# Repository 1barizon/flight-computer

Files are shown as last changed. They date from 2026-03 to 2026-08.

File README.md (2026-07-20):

# Avionics — Onboard Computer

> **v2.0 Flight Computer** for Serra Rocketry (#11 - Dedalo).
>
> OOP + FreeRTOS + 4-state FSM, validated against real flight data.
> Built for the ESP32-S3.

## Overview

Real-time avionics firmware for a sounding rocket. Runs on an **ESP32-S3**
under FreeRTOS, reading barometric (BMP585), inertial (LSM6DS3) and GPS
(NEO-8M) sensors to detect flight events and deploy the parachute at apogee.

- **Flight state machine**: IDLE → ASCENT → DESCENT → LANDED, with sub-event
  flags (liftoff, burnout, apogee, freefall, parachute)
- **Parachute deployment**: Apogee + stable negative Vz, 3-cycle
  confirmation, 50 m ground guard — validated against RocketPy + real flight data points
- **Telemetry**: 22-field CSV over LoRa @ 915 MHz to ground receiver
- **Logging**: SD card (primary) with LittleFS flash fallback
- **Safety**: NaN/Inf rejection, sensor fallback, TWDT watchdog, multi-condition parachute logic

## Architecture

```
firmware/
├── firmware.ino          # setup()/loop() — orchestrates init*Task()
├── config.h              # Pins, thresholds, radio parameters
├── sensors/              # ISensor implementations (BMP585, LSM6DS3, GPS)
├── flight/               # FreeRTOS tasks + FlightStateMachine
├── modules/              # Actuators/peripherals (servo, LoRa, buzzer, FS)
├── MODULOS.md            # Module reference
└── REFACTORING_PLAN.md   # v2.0 architecture specification
```

Two FreeRTOS cores with queue-based communication:

| Core | Task | Priority | Rate | Responsibility |
|---|---|---|---|---|
| **1** | `FlightControlTask` | 20 | 50 Hz | Sensors + FSM + parachute + watchdog |
| **0** | `TelemetryTask` | 5 | 5 Hz | GPS enrichment + LoRa + file + Serial |
| **0** | `LoggerTask` | 1 | — | Async log queue with level filter |

## Quick Start

### Arduino IDE (recommended)

1. Board: **ESP32-S3 Dev Module** (enable "USB CDC On Boot")
2. Open `firmware/firmware.ino`
3. Install libraries: `Adafruit BMP5xx`, `Adafruit LSM6DS3`, `TinyGPS++`,
   `ESP32Servo`, `LoRa by Sandeep Mistry`
4. Compile (`Ctrl+R`) and upload (`Ctrl+U`)

### Validate without hardware

```bash
python3 extras/FSM_tester/FSM_Tester.py       # FSM against 1,873 real data points
python3 extras/validate_telemetry_format.py    # 22-field telemetry alignment
```

## Key Specifications

| Parameter | Value |
|---|---|
| FlightControl rate | 50 Hz (20 ms) |
| Telemetry rate | 5 Hz (200 ms) |
| Parachute confirm | 3 consecutive Vz < −2 m/s |
| Ground guard | 50 m AGL |
| LoRa frequency | 915 MHz (Brazil/Americas ISM) |
| LoRa config | SF7, BW 125 kHz, CR 4/5, CRC on, +17 dBm |
| Storage | SD card (SPI) → LittleFS fallback |
| Sensor queue | 25 slots (∼2.4 KB) |
| Log queue | 50 slots (∼7.2 KB) |

## Documentation

- [`docs/software.md`](docs/software.md) — Software architecture
- [`docs/hardware.md`](docs/hardware.md) — Hardware specs, pinout, BOM
- [`docs/flowchart.md`](docs/flowchart.md) — FreeRTOS + FSM flow diagram
- [`AGENTS.md`](AGENTS.md) — AI agent coding guide
- [`CONTRIBUTING.md`](CONTRIBUTING.md) — How to contribute

## Repository Layout

```
firmware/   v2.0 firmware (OOP + FreeRTOS + FSM)
test/       Hardware validation sketches (sensors, servo, FSM)
docs/       software.md, hardware.md, telemetry-format.md, flowchart.md
hardware/   KiCad schematic + PCB + BOM
extras/     Scripts, FSM tester, format validator
```

## Status

All refactoring plan phases are **complete** — v2.0 is fully implemented and
documented. See [`CHANGELOG.md`](CHANGELOG.md) for the full release history.

## Team

Serra Rocketry — #11 Dedalo - LASC 2026

## License

Serra Rocketry. Contributions under the project license — see `CONTRIBUTING.md`.

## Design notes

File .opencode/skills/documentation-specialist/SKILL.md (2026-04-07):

---
name: documentation-specialist
description: Technical writer and documentation specialist for embedded systems and aerospace projects.
license: MIT
compatibility: opencode
---

## Expertise
- Technical documentation (user guides, API docs, architecture docs)
- Markdown and documentation tools (Mermaid, Doxygen)
- Code documentation standards
- README and contribution guidelines
- Release notes and changelogs

## Responsibilities
1. **Maintain Project Documentation**
   - Keep README.md up to date
   - Update CHANGELOG.md with each release
   - Document architecture decisions
   - Create user guides and tutorials

2. **Code Documentation**
   - Review Doxygen comments
   - Ensure all public APIs documented
   - Create code examples
   - Document configuration options

3. **Process Documentation**
   - Document workflows (build, test, deploy)
   - Create contributor guides
   - Write troubleshooting guides
   - Maintain FAQ

## Project Documentation Structure

```
flight-computer/
├── README.md                    # Project overview
├── CHANGELOG.md                 # Version history
├── CONTRIBUTING.md              # How to contribute
│
├── docs/
│   ├── hardware.md              # Hardware specifications
│   ├── software.md              # Software architecture
│   ├── flowchart.md             # System flowcharts
│   └── CDB.png                  # Block diagram
│
├── firmware/
│   ├── MODULOS.md               # Module documentation
│   ├── REFACTORING_PLAN.md      # v2.0 architecture
│   └── [code files with Doxygen comments]
│
└── extras/
    └── FSM_tester/
        └── explicacao.md        # FSM explanation
```

## Documentation Standards

### README.md Structure
```markdown
# Project Name

[Badge: Build Status] [Badge: License] [Badge: Version]

## Overview
Brief description of the project (2-3 sentences)

## Features
- Feature 1
- Feature 2

## Hardware Requirements
- Component 1
- Component 2

## Software Requirements
- Library 1
- Library 2

## Quick Start
1. Step 1
2. Step 2

## Documentation
- [Hardware Guide](docs/hardware.md)
- [Software Guide](docs/software.md)

## Contributing
See [CONTRIBUTING.md](CONTRIBUTING.md)

## License
[License information]

## Team
Team #100 - Serra Rocketry
```

### CHANGELOG.md Format
**Follow**: [Keep a Changelog](https://keepachangelog.com/)

```markdown
# Changelog

All notable changes to this project will be documented in this file.

The format is based on [Keep a Changelog](https://keepachangelog.com/en/1.0.0/),
and this project adheres to [Semantic Versioning](https://semver.org/spec/v2.0.0.html).

## [Unreleased]

### Added
- New feature X

### Changed
- Modified behavior Y

### Fixed
- Bug Z

## [2.0.0] - 2026-XX-XX

### Added
- FreeRTOS multi-task architecture
- 7-state FSM with validated thresholds
- BMP585 and LSM6DS3 sensor support
- OOP sensor abstractions (ISensor interface)

### Changed
- Migrated from procedural to OOP design
- Replaced BMP280 with BMP585
- Replaced MPU6050 with LSM6DS3

### Removed
- Old procedural sensor modules

## [1.0.0] - 2026-01-27

### Added
- Initial release
- BMP280 barometric sensor support
- MPU6050 IMU support
- GPS NEO-6M integration
- LoRa telemetry (RFM95W)
- Parachute deployment logic
- LittleFS data logging
- WiFi AP for data recovery

[Unreleased]: https://github.com/team100/flight-computer/compare/v2.0.0...HEAD
[2.0.0]: https://github.com/team100/flight-computer/compare/v1.0.0...v2.0.0
[1.0.0]: https://github.com/team100/flight-computer/releases/tag/v1.0.0
```

### Code Documentation (Doxygen)

#### File Header
```cpp
/**
 * @file BMP585Sensor.h
 * @brief BMP585 barometric pressure sensor driver with altitude calculation
 * 
 * This module provides an interface to the Bosch BMP585 barometric pressure
 * sensor. It calculates altitude based on barometric formula and computes
 * vertical velocity through numerical differentiation.
 * 
 * @author Team #100 - Serra Rocketry
 * @date 2026-04-01
 * @version 2.0.0
 * 
 * Hardware Requirements:
 * - BMP585 sensor connected via I2C
 * - I2C address: 0x77 (SDO high) or 0x76 (SDO low)
 * - Pull-up resistors: 4.7kΩ (internal to ESP32-C3)
 * 
 * Usage Example:
 * @code
 * BMP585Sensor baro;
 * 
 * void setup() {
 *   if (!baro.begin()) {
 *     Serial.println("Sensor initialization failed");
 *   }
 * }
 * 
 * void loop() {
 *   baro.update();
 *   float alt = baro.getAltitude();
 *   float vz = baro.getVerticalVelocity();
 * }
 * @endcode
 * 
 * @see firmware/REFACTORING_PLAN.md for architecture details
 * @see docs/hardware.md for wiring diagram
 */
```

#### Function Documentation
```cpp
/**
 * @brief Initializes the BMP585 sensor and calibrates base pressure
 * 
 * This function performs the following steps:
 * 1. Establishes I2C communication with sensor
 * 2. Verifies sensor ID (0x50 for BMP585)
 * 3. Configures oversampling and IIR filter
 * 4. Calibrates base pressure (10-sample average)
 * 
 * @return true if initialization successful, false on error
 * 
 * @note This function blocks for approximately 100ms during calibration
 * @warning Must be called in setup() before any update() calls
 * 
 * @see update() for non-blocking sensor reads
 */
bool begin();

/**
 * @brief Updates sensor readings and calculates derived values
 * 
 * Reads current pressure and temperature, then calculates:
 * - Altitude using barometric formula: h = 44330 * (1 - (P/P0)^0.1903)
 * - Vertical velocity using numerical differentiation: vz = Δh / Δt
 * 
 * @return void
 * 
 * @note Should be called at regular intervals (5Hz recommended)
 * @note Non-blocking (returns immediately)
 * 
 * Validation:
 * - NaN pressure readings are replaced with last known good value
 * - Altitude clamped to [-500, 50000] meters
 * - Vertical velocity clamped to [-200, 200] m/s
 * 
 * @see getAltitude() to retrieve calculated altitude
 * @see getVerticalVelocity() to retrieve calculated velocity
 */
void update();

/**
 * @brief Returns the current altitude above base pressure level
 * 
 * @return float Altitude in meters (positive = above base)
 * 
 * @note Altitude is relative to calibration point (launchpad)
 * @note Valid range: -500 to 50000 meters
 * @note Returns last valid value if sensor disconnected
 */
float getAltitude() const;
```

### Architecture Documentation

#### Decision Record Template
**File**: `docs/adr/001-freertos-migration.md`

```markdown
# ADR 001: Migrate to FreeRTOS Architecture

**Status**: Accepted  
**Date**: 2026-03-15  
**Deciders**: Team #100  

## Context
Current v1.0 firmware uses single-threaded Arduino loop() running at 5Hz.
This creates several issues:
1. Slow FSM response time (200ms loop period)
2. Cannot prioritize flight-critical tasks
3. Telemetry logging blocks flight control
4. Underutilizes ESP32 dual-core processor

## Decision
Migrate to FreeRTOS multi-task architecture with 3 tasks:
- **FlightControl**: 50Hz, Core 1, Priority 20 (flight-critical)
- **Telemetry**: 5Hz, Core 0, Priority 5 (non-critical)
- **Logger**: Low priority, Core 0 (background)

## Rationale
- **Real-time response**: 20ms FSM update vs 200ms previously
- **Prioritization**: Flight safety takes precedence over logging
- **Core separation**: Flight logic isolated from I/O operations
- **Scalability**: Easy to add tasks (e.g., camera control)

## Consequences

### Positive
- 10x faster FSM response time
- Flight control never blocked by slow operations
- Better CPU utilization (both cores active)
- Industry-standard RTOS patterns

### Negative
- Increased complexity (task synchronization)
- Higher RAM usage (~15KB for RTOS overhead)
- Requires mutex/queue understanding
- Longer development time (estimated +8 hours)

## Alternatives Considered
1. **Keep single-threaded** - Rejected: Too slow for safety-critical FSM
2. **Custom cooperative scheduler** - Rejected: Reinventing the wheel
3. **Bare metal dual-core** - Rejected: Complex synchronization

## Implementation
See `firmware/REFACTORING_PLAN.md` Phase 7 for details.

## References
- ESP32 Technical Reference Manual, Chapter 3 (RTOS)
- FreeRTOS Documentation: Task Priorities
- Similar implementation: Teensy Flight Computer (MIT Rocket Team)
```

### Mermaid Diagrams

#### FSM State Diagram
```markdown
## Flight State Machine

```mermaid
stateDiagram-v2
    [*] --> IDLE
    IDLE --> LIFTOFF: totalAccel > 15 m/s²<br/>height > 5m
    
    LIFTOFF --> BURNOUT: az < -8 m/s² OR<br/>totalAccel < 2 m/s²
    
    BURNOUT --> APOGEE: |vz| < 1 m/s AND<br/>az < -0.1 m/s²
    
    APOGEE --> FREEFALL: totalAccel < 11.5 m/s² AND<br/>vz < -5 m/s
    
    FREEFALL --> PARACHUTE: altitude < 750m OR<br/>|vz| > 80 m/s
    
    PARACHUTE --> LANDED: |vz| < 0.5 m/s AND<br/>height < 10m
    
    LANDED --> [*]
    
    note right of IDLE
        Initialize sensors
        Calibrate base pressure
    end note
    
    note right of PARACHUTE
        Deploy parachute
        Start WiFi AP
        Beacon buzzer
    end note
\```
```

#### Task Interaction Diagram
```markdown
## FreeRTOS Task Architecture

```mermaid
graph TB
    subgraph "Core 1 - Flight Critical"
        FC[FlightControl Task<br/>50Hz, Priority 20]
        FSM[Flight State Machine]
        SENS[Sensor Updates]
        PARA[Parachute Control]
        
        FC --> FSM
        FC --> SENS
        FSM --> PARA
    end
    
    subgraph "Core 0 - Non-Critical"
        TEL[Telemetry Task<br/>5Hz, Priority 5]
        LOG[Logger Task<br/>Low Priority]
        
        TEL --> LORA[LoRa Transmit]
        TEL --> SERIAL[Serial Output]
        LOG --> FS[File System]
    end
    
    subgraph "Shared Resources"
        QUEUE[(Sensor Data Queue)]
        MUTEX{Altitude Mutex}
    end
    
    FC -->|xQueueSend| QUEUE
    TEL -->|xQueueReceive| QUEUE
    
    FC -->|xSemaphoreTake| MUTEX
    TEL -->|xSemaphoreTake| MUTEX
    
    style FC fill:#f96,stroke:#333,stroke-width:2px
    style TEL fill:#9cf,stroke:#333,stroke-width:2px
    style LOG fill:#9cf,stroke:#333,stroke-width:2px
\```
```

## Documentation Review Checklist

### For New Features
- [ ] README.md updated with feature description
- [ ] CHANGELOG.md updated (Unreleased section)
- [ ] API documentation (Doxygen comments)
- [ ] Usage examples provided
- [ ] Hardware requirements documented (if applicable)
- [ ] Configuration options explained

### For Bug Fixes
- [ ] CHANGELOG.md updated (Fixed section)
- [ ] Root cause documented in issue/PR
- [ ] Prevention strategy explained

### For Refactoring
- [ ] Architecture Decision Record created
- [ ] Migration guide provided
- [ ] Breaking changes documented
- [ ] CHANGELOG.md updated (Changed section)

## Tools

### Generate Doxygen Docs
```bash
# Install Doxygen
sudo apt install doxygen graphviz

# Generate documentation
cd firmware
doxygen Doxyfile

# View in browser
firefox html/index.html
```

### Mermaid Live Editor
https://mermaid.live/

### Markdown Linting
```bash
# Install markdownlint
npm install -g markdownlint-cli

# Lint documentation
markdownlint docs/**/*.md
```

## Resources
- Project documentation: `docs/`
- Doxygen manual: https://www.doxygen.nl/
- Mermaid syntax: https://mermaid.js.org/
- Keep a Changelog: https://keepachangelog.com/
- Semantic Versioning: https://semver.org/

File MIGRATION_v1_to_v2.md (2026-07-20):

# Migration Guide: v1.0 → v2.0 (Flight Computer)

This document records the architectural decisions and concrete changes made
when moving the Flight Computer firmware from the v1.0 procedural design
(branch `main`, pre-refactor) to the v2.0 OOP + FreeRTOS design (branch
`dev-2026`). It is the rationale companion to `REFACTORING_PLAN.md` and the
`docs/` files — read it when you need to understand *why* something changed,
not just *what* the code looks like now.

## TL;DR

| Aspect | v1.0 (main, legacy) | v2.0 (dev-2026) |
|---|---|---|
| Architecture | Procedural `loop()` in one `firmware.ino` (~680 lines) | OOP + FreeRTOS, modular `sensors/` `modules/` `flight/` |
| Sensors | BMP280 + MPU6050 + NEO-6M | BMP585 + LSM6DS3 + NEO-8M |
| Flight logic | `handleParachute()` with altitude ceiling | `FlightStateMachine` (4 states + 7 sub-events) |
| Parachute | Deploy at `ALTITUDE_THRESHOLD = 750 m` | Deploy at **apogee** |
| Comms | LoRa 868 MHz, ad-hoc CSV | LoRa 915 MHz, v2.0 22-field format |
| Web UI | ESPAsyncWebServer on board | Removed (receiver provides web UI) |
| Storage | LittleFS, v1.0 CSV header | SD card (filesystem_module.h `setupStorage`), LittleFS fallback; 22-field v2.0 CSV |

## Side-by-side: Architecture

### Project structure

**v1.0** — flat, monolithic:

```
firmware/
├── firmware.ino              # ~680 lines: setup() + loop() + all logic
├── config.h
├── data/server/              # ESPAsyncWebServer web UI (index.html/js/css)
├── bmp280_sensor.h           # legacy sensor module
├── mpu6050_sensor.h
├── gps_module.h
├── lora_module.h
├── filesystem_module.h
├── parachute_module.h
└── buzzer_module.h
```

**v2.0** — modular OOP + FreeRTOS:

```
firmware/
├── firmware.ino              # thin entry point: setup() calls init*Task()
├── config.h                  # pins, thresholds, LoRa params
├── sensors/                  # ISensor abstraction
│   ├── ISensor.h
│   ├── BMP585Sensor.h/.cpp
│   ├── LSM6DS3Sensor.h/.cpp
│   └── GPSModule.h/.cpp
├── modules/                  # actuators / peripherals
│   ├── parachute_module.h    # owns ParachuteServo
│   ├── lora_module.h
│   ├── buzzer_module.h
│   └── filesystem_module.h
└── flight/                   # FreeRTOS tasks + FSM
    ├── SensorData.h
    ├── FlightStateMachine.h/.cpp
    ├── FlightControlTask.h/.cpp
    ├── TelemetryTask.h/.cpp
    └── LoggerTask.h/.cpp
```

### Data flow

**v1.0** — synchronous, single thread:

```
loop() [every INTERVAL ms]
  └─ readSensors()        # blocking I2C/UART reads
       └─ handleParachute()   # direct servo write if alt < 750 m
            └─ logData()      # append to LittleFS
                 └─ sendLoRa() # one long CSV string
```

**v2.0** — concurrent, queue-driven:

```
Core 1 (50 Hz, prio 20):  taskFlightControl
  ├─ BMP585/LSM6DS3 update()
  ├─ FlightStateMachine.update()  → detectParachute() at apogee
  ├─ deployParachute() via parachute_module
  └─ xQueueSend(sensorDataQueue)

Core 0 (5 Hz, prio 5):    taskTelemetry
  ├─ GPSModule.update()
  ├─ xQueueReceive(sensorDataQueue)  → newest sample
  ├─ assembleTelemetry()  → 22-field CSV
  └─ fan-out: Serial + sendLoRa() + appendFile()

Core 0 (low prio):        taskLogger
  └─ xQueueReceive(logQueue) → Serial print (level filter)
```

### Build / runtime footprint

| | v1.0 | v2.0 |
|--|---|---|
| Entry point | `loop()` does everything | `loop()` empty (`vTaskDelay(portMAX_DELAY)`) |
| Concurrency | none (blocking calls) | 3 FreeRTOS tasks, 2 cores |
| Real-time guarantee | none | FlightControl @50Hz isolated on Core 1 |
| Watchdog | none | TWDT armed inside `taskFlightControl` |

## Side-by-side: Code

### Entry point (`firmware.ino`)

**v1.0** — everything in `loop()`:

```cpp
void loop() {
  if (millis() - lastRead >= INTERVAL) {
    lastRead = millis();
    readSensors();
    handleParachute();   // direct: if (altitude < 750) servo.write(90);
    logData();
    sendLoRa();
  }
}
```

**v2.0** — thin setup, tasks own the work:

```cpp
void setup() {
  Serial.begin(115200);
  Wire.begin();
  pinMode(BUZZER_PIN, OUTPUT);
  if (!initFlightControlTask()) { Serial.println("FATAL"); ESP.restart(); }
  if (!initTelemetryTask())      { Serial.println("FATAL"); ESP.restart(); }
  if (!initLoggerTask())         { Serial.println("FATAL"); ESP.restart(); }
}

void loop() {
  vTaskDelay(portMAX_DELAY);   // all work runs in FreeRTOS tasks
}
```

### Parachute decision

**v1.0** — fixed altitude ceiling (`handleParachute`):

```cpp
const float ALTITUDE_THRESHOLD = 750.0;        // m
const float ALTITUDE_DROP_THRESHOLD = 10.0;   // m
const float VELOCITY_THRESHOLD = 80.0;        // m/s

void handleParachute() {
  if (altitude < ALTITUDE_THRESHOLD &&
      (peakAltitude - altitude) > ALTITUDE_DROP_THRESHOLD &&
      descentVelocity > VELOCITY_THRESHOLD) {
    servo.write(90);   // open
  }
}
```

**v2.0** — apogee detection in the FSM (`detectParachute`):

```cpp
// config.h
#define PARACHUTE_MIN_ALTITUDE 50.0f   // ground guard only
#define PARACHUTE_CONFIRM_VZ   -2.0f   // m/s
#define PARACHUTE_CONFIRM_CYCLES 3u

// FlightStateMachine::detectParachute()
bool detectParachute(float height, float vz) const {
  if (height < PARACHUTE_MIN_ALTITUDE) return false;     // never near ground
  if (vz < PARACHUTE_CONFIRM_VZ) {                       // stable negative Vz
    return (_parachuteConfirmCount >= PARACHUTE_CONFIRM_CYCLES);
  }
  return false;
}
// actuated by taskFlightControl → parachute_module.deployParachute()
```

### Sensor reading

**v1.0** — global sensor objects, free functions:

```cpp
Adafruit_BMP280 bmp;
Adafruit_MPU6050 mpu;

void readSensors() {
  float altitude = bmp.readAltitude(BASE_PRESSURE);
  sensors_event_t a, g;
  mpu.getEvent(&a, &g, &temp);
  // ... used directly, no type safety
}
```

**v2.0** — `ISensor` interface, polymorphism:

```cpp
class BMP585Sensor : public ISensor {
  bool begin() override;
  void update() override;          // reads + filters + derives Vz
  String getData() override;      // CSV fragment
  float getAltitude() const;
  float getVerticalVelocity() const;
};

// FlightControlTask calls through the interface:
_baro->update();
_imu->update();
float vz = _baro->getVerticalVelocity();
```

### Telemetry line

**v1.0** — ad-hoc CSV, receiver-incompatible ordering:

```cpp
String line = String(ID) + "," + Packet + "," + Time + "," +
              Latitude + "," + Longitude + "," + GPS_Altitude + "," +
              Satellites + "," + Date + "," + Hours + "," + Minutes + "," +
              Seconds + "," + BMP_Altitude + "," + Pressure + "," +
              AccX + "," + AccY + "," + AccZ + "," + GyroX + "," +
              GyroY + "," + GyroZ + "," + Temp + "," + ParachuteStatus;
```

**v2.0** — 22-field v2.0 format (see `docs/telemetry-format.md`):

```cpp
// TelemetryTask::assembleTelemetry()
String line =
  TEAM_ID + "," + millis + "," + count + "," + altp + "," + temp + "," +
  umi + "," + p + "," + gx + "," + gy + "," + gz + "," + ax + "," + ay + "," +
  az + "," + vz + "," + maxAltitude + "," + state + "," + alt + "," + lat + "," +
  lon + "," + sat + "," + parachute + "," + rssi;
```

### Radio configuration

**v1.0**:

```cpp
#define LORA_FREQ 868E6     // Europe
LoRa.setSyncWord(0xF3);
// SF/BW/CR left at library defaults
```

**v2.0**:

```cpp
#define LORA_FREQ 915E6     // Americas/Brazil, matches receiver
LoRa.setSyncWord(SYNC_WORD);          // 0xF3
LoRa.setSpreadingFactor(LORA_SF);     // 7
LoRa.setSignalBandwidth(LORA_BW);     // 125E3
LoRa.setCodingRate4(LORA_CR);         // 5
LoRa.setTxPower(LORA_TX_POWER);       // 17
```

## Decisions and rationale

### 1. OOP + FreeRTOS instead of a single procedural `loop()`

**v1.0**: all logic lived in `firmware.ino` with `readSensors()`,
`handleParachute()`, `logData()`, `sendLoRa()` called from `loop()` on a
`INTERVAL` timer. Hard to test, no real-time guarantees.

**v2.0**: sensor classes implement a common `ISensor` interface; flight logic
is split into three FreeRTOS tasks:

- `taskFlightControl` — Core 1, 50 Hz, priority 20 (sensors + FSM + deploy)
- `taskTelemetry` — Core 0, 5 Hz, priority 5 (GPS + assemble + fan-out)
- `taskLogger` — Core 0, low priority (log queue consumer)

Tasks communicate via `sensorDataQueue` and `logQueue`. The Arduino `loop()`
is intentionally empty (`vTaskDelay(portMAX_DELAY)`).

**Why**: deterministic timing for the safety-critical path, testable units,
cleaner separation. The monolithic `firmware.ino` is now only an entry point
that calls `init*Task()` functions.

### 2. Parachute at apogee, not at a fixed altitude ceiling

**v1.0**: `handleParachute()` opened the servo when altitude dropped below
`ALTITUDE_THRESHOLD = 750 m` with a velocity/drop guard
(`ALTITUDE_DROP_THRESHOLD = 10 m`, `VELOCITY_THRESHOLD = 80 m/s`).

**v2.0**: `FlightStateMachine::detectParachute()` opens at **apogee** — it
confirms a stable negative vertical velocity `Vz` for
`PARACHUTE_CONFIRM_CYCLES` cycles and never below `PARACHUTE_MIN_ALTITUDE`
(50 m ground guard only). The servo is actuated by `taskFlightControl` via
`parachute_module` (`ParachuteServo`).

**Why**: a fixed 750 m ceiling is wrong for a ~1000 m flight — it would deploy
far too early (or never, on shorter flights). Deploying at apogee maximizes
drag time and is validated against both a RocketPy simulation (apogee 951 m →
deploy 949.5 m) and real flight data (apogee 272 m → deploy 268 m). This was
the user-mandated decision ("deploy MUST open at apogee for ANY flight above
min altitude").

### 3. Telemetry format — v2.0 22-field, not a shrink to 19

**v1.0**: ad-hoc CSV, different field order than the receiver expected.

**v2.0**: a clean v2.0 wire format of 22 fields emitted by
the flight computer and parsed by the receiver
(`recovery-webui/components/receiver-lora`):

```
TEAM_ID,millis,count,altp,temp,umi,p,gx,gy,gz,ax,ay,az,vz,
maxAltitude,state,alt,lat,lon,sat,parachute,rssi
```

The receiver re-emits 24 fields (inserts local GPS `hora`/`data` + real `rssi`).
Single source of truth: `docs/telemetry-format.md`.

**Why shrinking the flight CSV to the old 19-fieldv1.0 layout**: 
keeps the richer v2.0 diagnostics (`vz`, `maxAltitude`, `state`,
`parachute`) and fixes a real parsing bug where the old 19-field parser shifted
`alt`/`lat`/`lon`/`sat`/`rssi` onto the wrong indices. Validated end-to-end
with `extras/validate_telemetry_format.py`.

### 4. Radio frequency 868 MHz → 915 MHz

**v1.0**: `LORA_FREQ 868E6` (Europe ISM).

**v2.0**: `LORA_FREQ 915E6` (Americas/Brazil ISM), matching the receiver.
Sync word `0xF3`, SF7, BW 125 kHz, CR 4/5, TX +17 dBm, CRC on — all aligned
explicitly in `lora_module.h` `setupLoRa()`.

**Why**: the flight computer and receiver must share the same frequency to
communicate at all.

### 5. Sensor hardware upgrade

| v1.0 | v2.0 | Note |
|---|---|---|
| BMP280 (barometer) | BMP585 | higher accuracy, same I2C 0x77 |
| MPU6050 (IMU) | LSM6DS3 | lower noise, same I2C |
| NEO-6M (GPS) | NEO-8M | more constellations, non-blocking UART |

### 6. Web interface removed from the board

**v1.0**: an `ESPAsyncWebServer` + `WiFi` UI served from `firmware/data/server/`.

**v2.0**: removed. Telemetry is recovered via the ground **receiver**, which
provides its own web UI and logs. The board focuses on flight-critical work
only.

### 7. Parachute actuation ownership

**v1.0**: servo written directly from flight logic (`Servo.h`).

**v2.0**: `parachute_module.h` is the sole owner of the `Servo ParachuteServo`
object (`setupServo()`, `deployParachute()`). The FSM/Task decide *when*; the
module *acts*. Dead code (`handleParachute`, `printBoth`, globals) was removed
in the Fase 9 cleanup.

## Files removed vs v1.0

- `firmware/firmware.ino` monolithic logic → replaced by modular `flight/` +
  `sensors/` + `modules/` + thin entry point.
- `firmware/data/server/` (web UI) → removed.
- Legacy sensor modules `bmp280_sensor.h`, `mpu6050_sensor.h`, `gps_module.h`
  → replaced by `sensors/BMP585Sensor.*`, `sensors/LSM6DS3Sensor.*`,
  `sensors/GPSModule.*`.
- Test sketches from v1.0 (`test/basico`, `test/sem_lora`, `test/server`,
  legacy `test/LittleFS`, `test/testeGPS`) → superseded by v2.0 tests
  (`test/FSM/FSM.ino`, `test/test_gps`, etc.).

## Files added in v2.0

- `firmware/sensors/` (ISensor, BMP585, LSM6DS3, GPS)
- `firmware/flight/` (SensorData, FlightStateMachine, FlightControlTask,
  TelemetryTask, LoggerTask)
- `firmware/modules/` (parachute, lora, buzzer, filesystem)
- `firmware/REFACTORING_PLAN.md`, `firmware/MODULOS.md`
- `docs/telemetry-format.md`, this file
- `extras/validate_telemetry_format.py`, `extras/FSM_tester/`

## Validation

- FSM: `python3 extras/FSM_tester/FSM_Tester.py` (real 1,873-point flight data)
- Telemetry: `python3 extras/validate_telemetry_format.py` (flight→receiver
  index match)
- Parachute: validated with RocketPy simulation + real flight CSV.

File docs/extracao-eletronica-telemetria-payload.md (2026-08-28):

# Extração — Setor de Eletrônica, Telemetria e Payload

> **Fonte:** repositório `flight-computer` (branch `dev-2026`, HEAD `130149c`)
> **Para:** preenchimento do relatório do setor (competição 7ª LASC)
> **Data da extração:** 2026-08-06
> **Status:** v2.0 implementada (firmware completo em OOP); eletrônica em
> transição — schematic v2.0 existe mas PCB de voo ainda não roteada

---

## 1. System Architecture & CONOPS

### 1.1 Descrição geral do sistema eletrônico

O computador de voo é um sistema embarcado baseado em **ESP32-S3**
(DevKitC-1 N8R2), dois núcleos, 8 MB Flash, 2 MB PSRAM, executando
**FreeRTOS** com arquitetura orientada a objetos (v2.0). O sistema é
projetado para missões de foguetes suborbitais de curta duração (até
20 minutos), com a responsabilidade crítica de **abrir o paraquedas no
apogeu** de forma autônoma e sem feedback de confirmação mecânica.

O projeto transita de uma PCB protótipo (ESP32-C3 SuperMini + BME280 +
ICM-20602, uma camada, 4 componentes SMD) para a placa definitiva v2.0
(ESP32-S3 + BMP585 + LSM6DS3 + GPS M8N + LoRa 915 MHz + SD + step-down),
cujo schematic existe mas ainda não foi roteado. Durante a fase atual, o
firmware v2.0 é validado na placa DevKitC em bancada.

**Princípios de projeto do firmware:**
- Todas as decisões de deploy do paraquedas são **one-shot** (uma única
  vez, idempotente) e baseadas em **múltiplas camadas de redundância**
  independentes entre si.
- Dados de voo são gravados localmente (SD ou flash interna) como fonte
  primária; a telemetria LoRa é *best-effort* — o sistema nunca para de
  gravar por causa do link de rádio.
- Se qualquer componente de sensor falha, o sistema **não para** — usa
  fallbacks para os últimos valores válidos ou sensores redundantes.

### 1.2 Subsistema de hardware

| Subsistema | Componente | Função | Interface | Observações |
|---|---|---|---|---|
| Processador | ESP32-S3 DevKitC-1 N8R2 | Controle central,FreeRTOS, 2 núcleos | — | 240 MHz, 512 KB SRAM, 8 MB Flash, 2 MB PSRAM |
| Barômetro | BMP585 (Bosch) | Altitude barométrica, pressão, temperatura, Vz derivado no firmware | I2C (0x77) | 300–1250 hPa; ±0,5 hPa absoluta, ±0,06 hPa relativa; resolução ~0,01 hPa |
| IMU | LSM6DS3 (STMicroelectronics) | Aceleração (±16 g) e giroscópio (±2000 °/s) | I2C (0x6A) | Usado como sensor primário para detecção de queda livre (backstop) e contingência do barômetro congelado |
| GPS | u-blox NEO-8M / M8N | Geolocalização (lat/lon/alt) e tempo (nome do arquivo CSV) | UART (NMEA, não-bloqueante) | Multi-constelação: GPS + GLONASS + Galileo + BeiDou; sensibilidade −167 dBm; fix cold 26 s, hot 1 s |
| Telemetria | RFM95W HopeRF | Link de rádio LoRa 915 MHz (Brasil/Américas) | SPI (SCK=4, MISO=2, MOSI=3, CS=5, RST=6, DIO0=7) | SF7, BW125 kHz, CR 4/5, CRC on, TX +17 dBm; alcance ~4 km campo aberto |
| Armazenamento primário | MicroSD (SPI) | Gravação CSV 22 campos a 5 Hz (~4 KB/s) | SPI (bus compartilhado com LoRa, CS=12) | Cartão class 10; formato FAT32 |
| Armazenamento fallback | LittleFS (flash interna) | Fallback automático se SD falhar | Interno (NVS flash) | Capacidade limitada (~4 MB); se SD e LittleFS falharem, dados vão apenas para Serial |
| Atuador | Servo metálico ~4,8 kg·cm | Libera a porta do compartimento do paraquedas no apogeu | PWM (GPIO 7) | **50° (fechado) → 135° (ejeção)** — ângulos de bancada 2026-08-27; acionamento one-shot, sem feedback mecânico |
| Sinalização | Buzzer **passivo** | Beeps de status na inicialização (sucesso/falha) e alarme em safe-hold | GPIO 6 | Piezo passivo: exige onda quadrada via `tone()`/LEDC; **ressonância 2700 Hz** (varredura de bancada 27/08) — DC não produz som |
| Potência (estágio 1) | XL4015 step-down 5 A | Conversão DC-DC bateria → 5 V (servo, buzzer, GPS) | — | Substituiu o Mini-560 (27/08) após colapso sob pico do servo na bateria (unidade defeituosa; ver FMECA F16). Dropout ~1,5-2 V (assíncrono) — headroom aperta com 2S em fim de descarga |
| Potência (baterias) | 3× 18650 Li-ion paralelo | Fonte primária de energia | — | 3,7 V nominal, ~6000 mAh total; autonomia estimada 4–6 h |

### 1.3 Arquitetura de software (FreeRTOS)

O firmware é estruturado em três tarefas FreeRTOS concorrentes, duas
executadas no Core 0 (comunicação/armazenamento) e uma no Core 1
(controle de voo em tempo real). A comunicação entre tarefas ocorre
exclusivamente via filas (queues) — não há variáveis compartilhadas entre
tasks, eliminando condições de corrida por construção.

**Tarefa 1 — `taskFlightControl` (Core 1, prioridade 20, 50 Hz)**
Responsabilidade: leitura sequencial dos sensores (BMP585 → LSM6DS3),
execução da FSM, detecção e acionamento do paraquedas, alimentação do
watchdog (TWDT), coleta de métricas de execução (ciclos, overruns, queue
drops, tempo máximo de ciclo). Esta é a tarefa mais crítica do sistema
— sua perda (travamento) ativa o watchdog e provoca reboot, mas o estado
da FSM é restaurado do NVS, garantindo que o deploy possa ocorrer mesmo
após o reboot.

**Tarefa 2 — `taskTelemetry` (Core 0, prioridade 5, 5 Hz)**
Responsabilidade: atualização não-bloqueante do GPS (NMEA feed), drenagem
da fila de sensores (consome apenas a amostra mais recente, descartando
backlog de 200 ms), enriquecimento com fix GPS, montagem do CSV 22 campos
via `snprintf` (uma única conversão — não fragmenta heap), fan-out em três
canais simultâneos: Serial (debug), LoRa (receptor em solo) e arquivo
(SD ou LittleFS). O formato CSV é idêntico ao esperado pelo receptor
`recovery-webui/components/receiver-lora`.

**Tarefa 3 — `taskLogger` (Core 0, prioridade baixa, evento)**
Responsabilidade: recebe mensagens da fila de logs (50 slots) com filtro
de nível e imprime no Serial. Usado para diagnóstico e rastreio de
eventos de segurança (ARM, deploy, erros de watchdog).

**Parâmetros-chave de execução:**

| Parâmetro | Valor | Justificativa |
|---|---|---|
| Período FlightControl | 20 ms (50 Hz) | Resolução suficiente para detectar apogeu com 20 ms de latência (vz muda ~0,5 m/s por ciclo no apogeu) |
| Período Telemetry | 200 ms (5 Hz) | Balanço entre taxa de amostragem para o receptor e janela de TX LoRa |
| Tamanho da fila de sensores | 25 slots | FlightControl produz 10× mais rápido que Telemetry; fila absorve variações de timing |
| Tamanho da fila de logs | 50 slots | Suficiente para burst de logs durante初始化 |
| Stack da FlightControlTask | 8192 bytes | Mínimo necessário para BMP585Sensor + LSM6DS3Sensor + FlightStateMachine + buffers |
| Stack da TelemetryTask | 4096 bytes | GPSModule + montagem de String (snprintf em buffer fixo 256 bytes) |
| Timeout do watchdog | 10 s | Mais longo que o período de voo (~10 s até apogeu), para não reiniciar durante a subida |

### 1.4 Lógica algorítmica de acionamento da recuperação

O sistema de recuperação é a função mais crítica do computador de voo.
Ele é implementado como uma **Finite State Machine (FSM) de 4 estados**
com 7 flags de sub-evento, projetada com múltiplas camadas de defesa
independentes para garantir que o paraquedas abra mesmo em caso de falhas
cascata.

**FSM principal:** `IDLE → ASCENT → DESCENT → LANDED`

**Sub-eventos (flags booleanas, uma vez setadas nunca são limpas até reset):**
- `liftoff`: aceleração total > 15,0 m/s² (3× gravidade — limiar acima
  de qualquer vibração realista no solo)
- `burnout`: aceleração na direção vertical < −8 m/s² OU aceleração
  total < 2 m/s², com altitude > 50 m e vz > 2 m/s (sub-evento
  informativo, não muda o estado)
- `apogee`: |vz| < 1,0 m/s (detecção por vz do barômetro; o gate de az
  foi removido em 2026-08-05 por pêndulo/bias do acelerômetro em voo real)
- `freefall`: aceleração total < 3 m/s² + vz < −5 m/s + altura > 100 m
- `parachute`: detectado pelo `detectParachute()` (abaixo)

**Cadeia de deploy (Opção A — abre no apogeu, inegociável):**

1. **Armamento na rampa (risco nº2):** antes do voo, o operador envia o
   comando `ARM` via Serial. O firmware limpa o snapshot NVS, re-captura
   a `base_pressure` (pressão atmosférica local) e zera o `maxAltitude`.
   Se a altitude derivar mais de −10 m por 3 s na rampa (drift do
   barômetro por mudança de temperatura), o sistema faz *re-zero*
   automático da pressão base. O ARM é recusado se o voo já começou
   (`maxAltitude > 10 m`) ou se o paraquedas já foi aberto.

2. **Liftoff:** quando a aceleração total (vetor filtrado com IIR,
   α=0,2) ultrapassa 15,0 m/s² por três ciclos consecutivos, a FSM
   transita de `IDLE` para `ASCENT`. A filtragem IIR com semente no
   primeiro valor real evita transições falsas por ruído de arranque.

3. **Apogeu:** quando |vz| cruza 1,0 m/s (vz do barômetro), a FSM
   transita de `ASCENT` para `DESCENT` e zera o contador de confirmação
   do paraquedas. A remoção do gate de az resolveu o problema de pêndulo
   onde o bias do acelerômetro (az = +2,81 m/s² em repouso no voo real)
   impedia a detecção do apogeu.

4. **Confirmação de descida (anti-oscilação):** o deploy do paraquedas
   requer `vz < −2,0 m/s` por **3 ciclos consecutivos** (60 ms a 50 Hz).
   Se durante esses ciclos o vz voltar a ser ≥ −2 m/s (oscilação do
   barômetro), o contador reseta para zero. Isso impede deploys falsos
   por ruído de quantização (50 Hz resolve vz em ~0,1 m/s; validado com
   0 deploys prematuros em 1.873 pontos de voo real).

5. **Acionamento do servo:** uma vez que `_parachuteDeployed` é setado
   como `true`, o FlightControlTask chama `ParachuteServo.write(SERVO_OPEN)`
   (comando PWM único, ângulo 0°). A flag `g_parachuteActuated` impede
   qualquer re-acionamento futuro. Se ocorrer reboot mid-flight, o NVS
   restaura `_parachuteDeployed` e o `setupServo(keepOpen=true)` mantém o
   servo na posição aberta.

**Contingências independentes da FSM (redundância por camadas):**

| Camada | Mecanismo | Gatilho | O que faz |
|---|---|---|---|
| 1. FSM principal | `detectParachute()` | Apogeu + vz < −2 m/s por 3 ciclos | Deploy normal |
| 2. Backstop de queda livre | `checkFreefallBackstop()` | acc < 3 m/s² por 1 s + vz < −5 m/s + altura > 50 m | Deploy mesmo se FSM travada |
| 3. Contingência barômetro congelado | `checkBaroStaleContingency()` | Barômetro sem leitura válida por 2 s + IMU detecta queda livre + `maxAltitude` último bom > 50 m | Deploy usando apenas IMU |
| 4. Guarda de solo | `PARACHUTE_MIN_ALTITUDE` | Altura < 50 m | Bloqueia deploy perto do solo |
| 5. Armamento / re-zero | Comando `ARM` | Operador na rampa | Limpa estado e recalibra |

Cada camada é executada independentemente no loop da tarefa FlightControl,
com seus próprios filtros IIR e contadores de ciclo, sem compartilhar
estado entre si. Mesmo que duas camadas falhem simultaneamente, a
terceira pode garantir o deploy.

### 1.5 Arquitetura da carga útil (Payload)

O "payload" do computador de voo é a **própria aquisição de dados
científicos do voo** — não há módulo de payload separado. O sistema
adquire e transmite 22 campos de dados por pacote, a 5 Hz, em formato
CSV alinhado ao protocolo do receptor em solo.

**Campos adquiridos (22 por pacote):**

| # | Campo | Tipo | Unidade | Fonte | Descrição |
|---|---|---|---|---|---|
| 0 | TEAM_ID | string | — | fixo (config.h) | Identificador do time (ex.: `#11`) |
| 1 | millis | uint32 | ms | millis() | Tempo desde boot |
| 2 | count | uint32 | — | contador | Número sequencial do pacote |
| 3 | altp | float | m | BMP585 | Altitude barométrica |
| 4 | temp | float | °C | BMP585 | Temperatura |
| 5 | umi | float | % | placeholder (0) | Umidade — sem sensor instalado |
| 6 | p | float | hPa | BMP585 | Pressão atmosférica |
| 7–9 | gx/gy/gz | float | rad/s | LSM6DS3 | Componentes do giroscópio |
| 10–12 | ax/ay/az | float | m/s² | LSM6DS3 | Componentes da aceleração |
| 13 | vz | float | m/s | BMP585 (derivado) | Velocidade vertical |
| 14 | maxAltitude | float | m | BMP585 | Altitude máxima atingida |
| 15 | state | int | — | FSM | Estado de voo (0=IDLE a 3=LANDED) |
| 16 | alt | float | m | GPS | Altitude GPS (nan se sem fix) |
| 17 | lat | float | graus | GPS | Latitude |
| 18 | lon | float | graus | GPS | Longitude |
| 19 | sat | uint8 | — | GPS | Número de satélites |
| 20 | parachute | int | 0/1 | FSM | Flag de deploy (1 = aberto) |
| 21 | rssi | int | dBm | receptor (overwrite) | Placeholder 0; receptor substitui pelo RSSI real medido |

**Canais de saída simultâneos:**
- **Serial** (115200 baud): formato legível para monitor serial
- **LoRa** (915 MHz): formato CSV 22 campos para o receptor em solo
- **Arquivo** (SD ou LittleFS): formato CSV 22 campos em disco

A telemetria é *best-effort*: se o LoRa não conseguir transmitir ou o
arquivo não puder ser escrito, o sistema continua operando normalmente.
Os dados locais (SD/LittleFS) são a **fonte primária** de dados de voo.

**Receptor:** o módulo `recovery-webui/components/receiver-lora` recebe
o pacote LoRa, substitui o campo `rssi` pelo valor real medido, insere
hora/data GPS locais (24 campos no total) e re-transmite para a WebUI.

---

## 2. Weights, Measures & Performance

### 2.1 Dimensões físicas

O computador de voo é composto por uma placa de circuito impresso (PCB)
de dimensões compactas para caber na baia de aviônica do foguete. A
dimensão documentada mais confiável é a do conjunto completo (placa +
baterias + fiação + suportes), que deve caber dentro da baia com espaço
para ventilação e acesso aos conectores.

| Item | Dimensão | Fonte |
|---|---|---|
| PCB definitiva v2.0 (contorno no KiCad) | 47,5 × 40 mm | `electronics.kicad_pcb` |
| Dimensão aproximada do conjunto completo | 125 × 50 × 30 mm (com componentes e fiação) | `docs/hardware.md` — referência do projeto CDB; **validar após o leiaute final** |
| Baia de aviônica | 125 × 50 mm (diâmetro × comprimento, encaixe na ogiva) | `docs/hardware.md` |
| Bateria | 3× células 18650 em paralelo (~18 mm × 65 mm cada) | `docs/hardware.md` |

> **Nota:** a dimensão de 125 × 50 × 30 mm refere o projeto legado CDB.
> O leiaute da placa v2.0 pode ser diferente — precisa ser medido após
> a rotação final da PCB.

### 2.2 Massas

A massa do conjunto aviônico é um parâmetro crítico para o cálculo de
centro de gravidade (CG) e estabilidade do foguete. A seguir, os valores
conhecidos e as lacunas que precisam ser preenchidas.

| Componente | Massa | Status | Observações |
|---|---|---|---|
| Servo do paraquedas | ~9 g (doc.) ou ~55 g (estimativa para 4,8 kg·cm) | ⚠️ **Conflito** | `docs/hardware.md` diz "metal gears, ~4,8 kg·cm, ~9 g"; 9 g é faixa de micro servo (~1,8 kg·cm) enquanto 4,8 kg·cm é faixa de servo ~55 g. **Identificar o modelo real e ajustar antes de publicar.** |
| ESP32-S3 DevKitC-1 | ~10 g (estimativa) | 🟡 Medido por referência | Inclui antena IPEX, headers e reguladores onboard |
| BMP585 breakout | ~2 g | 🟡 Estimativa | Módulo I2C, ~13×11 mm |
| LSM6DS3 breakout | ~1 g | 🟡 Estimativa | Módulo I2C, ~13×11 mm |
| GPS M8N + antena | ~10 g (módulo) + ~3 g (antena) | 🟡 Estimativa | Antena patch externa |
| RFM95W LoRa | ~3 g | 🟡 Estimativa | Módulo sem antena; antena SMA externa ~5 g |
| SD card (microSD 32 GB) | ~0,5 g | 🟡 Referência | |
| Mini-360 step-down | ~3 g | 🟡 Estimativa | Módulo DC-DC |
| Buzzer | ~2 g | 🟡 Estimativa | |
| Bateria (3× 18650 paralelo) | ~140 g (3 × 47 g) | ✅ Padrão | Células típicas Samsung 30Q / LG MJ1 |
| Fiação + conectores | ~15 g | 🟡 Estimativa | Inclui jumper headers, fios servo, conector BNC |
| PCB (placa) | ~10 g | 🟡 Estimativa | FR4, 2 camadas, ~50×40 mm |
| Standoffs M3 (4×) | ~5 g | 🟡 Estimativa | Parafusos + porcas |
| **Total estimado do conjunto** | **~210 g** | 🟡 **Estimativa** | **Medir em balança de precisão antes do relatório** |

> **Ação necessária:** pesar todos os componentes individualmente e o
> conjunto montado. O conflito de massa do servo (9 g vs 55 g) altera
> significativamente o CG do foguete.

### 2.3 Balanço de potência

**Fonte de alimentação:**
- 3× células 18650 Li-ion em paralelo (3,7 V nominal, ~6.000 mAh)
- Autonomia estimada: 4–6 h (baseada em consumo teórico; não medida em voo)
- Conversão DC-DC (LM2596 / MINI-360): duas saídas reguladas
  - **3,3 V @ 3 A** — alimenta ESP32-S3, sensores I2C (BMP585, LSM6DS3),
    módulo LoRa (parcialmente)
  - **5 V @ 3 A** — alimenta servo do paraquedas, buzzer, GPS M8N
  - Eficiência típica: ~85%

**Consumo por componente:**

| Componente | Corrente típica | Pico | Observação |
|---|---|---|---|
| ESP32-S3 (2 cores, 240 MHz) | ~80 mA | ~120 mA (WiFi TX, não usado) | Medido em datasheet; não inclui periféricos |
| BMP585 (I2C, 50 Hz) | ~3,2 mA | ~700 µA (medida) | Datasheet Bosch; modo normal |
| LSM6DS3 (I2C, 50 Hz) | ~0,9 mA | ~1 mA | Datasheet STMicro |
| GPS M8N (UART) | ~25 mA | ~35 mA (aquisição) | Fix: ~25 mA continuous |
| LoRa RFM95W (TX +17 dBm) | ~120 mA | ~120 mA (durante TX) | RX ~12 mA; standby ~1,2 mA |
| Servo (abertura sob carga) | — | ≤ 1.500 mA (critério de bancada) | Pico momentâneo; stall até 2.000 mA |
| Servo (stall, rotor travado) | ~1.200 mA | ≤ 2.500 mA (critério teto) | Medido com multímetro peak-hold |
| Buzzer (ativo) | ~30 mA | ~30 mA | Só durante初始化 (beeps de ~200 ms) |
| MicroSD (gravação) | ~30 mA | ~80 mA (写入) | Class 10 |
| LittleFS (flash interna) | ~10 mA | ~20 mA | Gravação na flash interna |

**Análise de margem no rail de 5 V:**

O rail de 5 V alimenta o servo, buzzer e GPS M8N compartilhando a mesma
fonte (BEC/MINI-360, teto 3 A). O pior caso de consumo é quando o servo
está em stall (rotor travado):

| Consumidor | Corrente |
|---|---|
| LoRa (TX) | 120 mA |
| Buzzer | 30 mA |
| Servo (stall pior caso) | 2.500 mA |
| GPS M8N | 25 mA |
| **Total** | **2.675 mA** |
| **Teto da fonte** | **3.000 mA** |
| **Margem** | **325 mA** |

A margem de 325 mA é adequada para operação nominal, mas se a fonte
tiver queda de tensão (bateria enfraquecida, regulador com ripple),
a tensão de 5 V pode cair — reduzindo o torque do servo (que depende
de 5 V) e potencialmente causando reset do ESP32 se a tensão de 3,3 V
também cair. **Este cenário de falha dupla** (servo perde torque + ESP32
reseta) foi identificado como risco residual no teste de bancada.

### 2.4 Performance dos sensores

| Sensor | Parâmetro-chave | Valor | Fonte |
|---|---|---|---|
| BMP585 | Precisão absoluta / relativa | ±0,5 hPa / ±0,06 hPa | Datasheet Bosch |
| BMP585 | Faixa operacional | 300–1250 hPa | Datasheet Bosch |
| BMP585 | Taxa de amostragem | Configurável até 200 Hz; usado a 50 Hz | config.h |
| LSM6DS3 | Aceleração | ±2/4/8/16 g (configurado: ±16 g) | Datasheet ST |
| LSM6DS3 | Giroscópio | ±125/250/500/1000/2000 °/s (configurado: ±2000 °/s) | Datasheet ST |
| NEO-8M / M8N | Sensibilidade | −167 dBm | Datasheet u-blox |
| NEO-8M / M8N | Fix (cold/hot) | 26 s / 1 s | Datasheet u-blox |
| NEO-8M / M8N | Acurácia horizontal | ±2,5 m CEP | Datasheet u-blox |
| NEO-8M / M8N | Constelações | GPS + GLONASS + Galileo + BeiDou | Datasheet u-blox |
| RFM95W | Sensibilidade | −139 dBm (SF12, BW125k) | Datasheet HopeRF |
| RFM95W | TX power | +20 dBm max (configurado: +17 dBm) | config.h |
| RFM95W | Alcance estimado | ~4 km campo aberto | Referência de projeto |

### 2.5 Parâmetros de telemetria (LoRa)

| Parâmetro | Valor | Justificativa |
|---|---|---|
| Frequência | 915 MHz | Faixa permitida no Brasil/Américas (ANATEL) |
| Spreading Factor | 7 | Equilíbrio entre alcance e taxa; SF7 = ~5,5 kbps |
| Bandwidth | 125 kHz | Padrão LoRa; compatível com receptor |
| Coding Rate | 4/5 | Correção de erro leve; baixa sobrecarga |
| Sync Word | 0xF3 | Rede exclusiva (apenas satélite + receptor) |
| CRC | Habilitado | Detecção de erros no pacote |
| TX Power | +17 dBm | Máximo do módulo; maximiza alcance |
| Pacotes por segundo | ~5 Hz | Alinhado com período da TelemetryTask |

---

## 3. Risk Assessment (Apêndice)

### 3.1 Visão geral da abordagem de segurança

O computador de voo é classificado como **sistema de segurança crítica**
— sua falha (não abrir o paraquedas) resulta em perda total do veículo.
A abordagem de segurança segue o princípio de **defesa em profundidade**:
múltiplas camadas independentes de detecção e mitigação, de modo que
nenhuma falha isolada possa impedir o deploy.

A análise abaixo cobre as falhas eletrônicas mapeadas, seus impactos no
sistema, as mitigações implementadas no firmware e hardware, e os riscos
residuais que permanecem mesmo com todas as mitigações ativas.

**Critérios de severidade usados:**
- **Crítica (10):** perda total do veículo
- **Alta (7–9):** perda de função crítica / missão comprometida
- **Média (4–6):** degradação significativa mas recuperável
- **Baixa (1–3):** efeito menor ou nenhum impacto no voo

### 3.2 Falhas eletrônicas mapeadas

#### F01 — Perda de sinal RF (LoRa)

O módulo LoRa pode perder o link com o receptor em solo devido a
obstáculos, interferência, distância excessiva, ou mau contato nos
pinos SPI durante vibração de voo.

**Impacto:** o sistema perde a telemetria em tempo real, mas a gravação
local (SD/LittleFS) continua normalmente. A missão de voo não é
comprometida — os dados são recuperados em solo após o pouso. A
perda de telemetria impede apenas o monitoramento em tempo real pela
equipe.

**Mitigações implementadas:**
- Telemetria LoRa é classificada como *best-effort* por design — o
  sistema nunca aguarda confirmação de recepção antes de transmitir
  o próximo pacote.
- O receptor (`recovery-webui`) registra RSSI real medido, permitindo
  diagnóstico pós-voo da qualidade do link.
- Os dados são gravados localmente como fonte primária; o LoRa é
  canarinho na mina, não o sistema de gravação.

**Status:** ✅ Implementado e validado.

#### F02 — Falha do barômetro (BMP585 congela)

O BMP585 pode congelar durante o voo devido a falha na comunicação I2C
(interferência eletromagnética, solda fria, vibração rompendo contato),
resultando em altitude e velocidade vertical congeladas nos últimos
valores válidos. Esses valores são plausíveis (não NaN), portanto a
validação padrão de NaN/Inf não os detecta.

**Impacto:** sem leitura válida de altitude/vz, a FSM e o backstop de
queda livre não conseguem detectar o apogeu nem a queda livre — ambos
dependem do barômetro. O paraquedas não abriria.

**Mitigações implementadas:**
- **Contingência `BARO_STALE`:** detecta quando o barômetro não produz
  leitura válida há mais de 2 segundos (`BARO_STALE_AGE_MS`). Quando
  o barômetro está congelado E o IMU detecta queda livre sustentada
  (acc < 3 m/s² por 125 ciclos = 2,5 s) E o último `maxAltitude`
  válido era superior a 50 m, o sistema aciona o paraquedas usando
  apenas dados do IMU.
- Esta contingência tem seu próprio filtro IIR, latch de liftoff e
  contador de ciclo, totalmente independentes da FSM e do backstop.
- Validada com testes unitários (`validate_baro_stale.py`).
- **Causa raiz mitigada:** o firmware `setup()` inicializa o SPI bus
  com os pinos corretos do LoRa antes de chamar `SD.begin()`, evitando
  que o SD use pinos errados e caia silenciosamente no LittleFS.

**Status:** ✅ Implementado e validado.

#### F03 — Travamento do microcontrolador (ESP32-S3)

O ESP32 pode travar devido a deadlock em operações de I2C/SPI,
overflow de stack em tarefas, corrupção de heap, ou falha de
alocação de memória. Se a tarefa FlightControl não alimentar o
watchdog por mais de 10 segundos, o TWDT provoca reboot.

**Impacto:** se o reboot ocorrer durante o voo, o firmware perde o
contexto de execução. Se o paraquedas ainda não foi aberto, a FSM
precisa restaurar corretamente do NVS para que o deploy possa ocorrer
no estado restaurado.

**Mitigações implementadas:**
- **TWDT (Task Watchdog Timer):** alimentado a cada ciclo da
  FlightControlTask. Timeout de 10 segundos — mais longo que o tempo
  total de voo até apogeu (~10 s para 273 m), evitando reboot
  prematuro durante a subida.
- **Persistência NVS:** o estado da FSM, flags de sub-evento, contagem
  de confirmação, `basePressure` e `maxAltitude` são salvos em NVS a
  cada transição de estado. Se ocorrer reboot mid-flight, o firmware
  restaura exatamente o estado anterior.
- **Safe-hold:** se qualquer初始化 falhar, o firmware não chama
  `ESP.restart()` — entra em loop infinito com buzzer piscando,
  preservando o estado para diagnóstico.
- **`setupServo(keepOpen)`:** se o reboot ocorre com paraquedas já
  aberto, o servo é mantido na posição aberta (não fecha a porta em
  cima do velame já liberado).

**Status:** ✅ Implementado.

#### F04 — Falha no sensor IMU (LSM6DS3 congela)

O LSM6DS3 pode falhar por I2C hang (mesmos mecanismos do barômetro),
resultando em aceleração congelada no último valor válido.

**Impacto:** o backstop de queda livre e a contingência do barômetro
congelado dependem do IMU para medir aceleração. Se ambos os sensores
falharem simultaneamente, nenhuma contingência pode operar — o
paraquedas não abriria.

**Mitigações implementadas:**
- Validação de NaN/Inf em cada leitura do IMU (rejeita frames
  corrompidos).
- O backstop e a contingência BARO_STALE calculam seu próprio filtro
  IIR independentemente — se o IMU retorna zeros (congelado), o
  backstop não dispara (acc = 0 < 3, mas vz = 0, não < −5, logo
  não ativa). Se o IMU retorna último valor válido (ex.: 9,8 m/s²
  em queda livre), o backstop não dispara (acc > 3).
- **Gap identificado:** não existe equivalente ao BARO_STALE para o
  IMU — se o IMU congela, as contingências que dependem dele ficam
  cegas. É uma falha de modo comum (CMB) entre backstop e BARO_STALE.

**Status:** 🟡 Parcialmente mitigado. Recomendação: implementar
detecção de IMU stale (idade da última leitura válida) similar ao
BARO_STALE, e considerar sensor barométrico secundário.

#### F05 — Falha do GPS

O GPS pode perder fix (satélites obstruídos), falhar na inicialização
(I2C/UART), ou retornar dados corrompidos.

**Impacto:** a perda do GPS impede a gravação de latitude/longitude e
do timestamp no nome do arquivo CSV, mas **não afeta o deploy do
paraquedas** — o deploy é determinado exclusivamente por barômetro + IMU.
O campo `alt` no CSV fica "nan", e o nome do arquivo usa "NOFIX".

**Mitigações implementadas:**
- O GPS é atualizado de forma não-bloqueante (NMEA feed a cada ciclo
  de 200 ms da TelemetryTask).
- Se o GPS não inicializa, o firmware continua sem fix (log de aviso).
- O campo `gps_valid` no CSV indica explicitamente se o fix é válido.

**Status:** ✅ Implementado. Risco: baixo (não afeta a função crítica).

#### F06 — Liftoff falso na rampa (vibração)

Vibrações do solo, vento, ou manuseio na rampa podem produzir
acelerações > 15 m/s², causando transição prematura para ASCENT.
Se ocorrer um reboot durante essas vibrações, o NVS restaura ASCENT
e o firmware fica preso no estado de subida sem nunca deployar.

**Impacto:** se o reboot happen no solo, o firmware restaura ASCENT
e nunca re-detecta liftoff (o limiar só é verificado em IDLE). O
paraquedas não abriria.

**Mitigações implementadas:**
- **Comando ARM (risco nº2):** limpa o NVS, zera `maxAltitude`,
  recalibra `base_pressure`. O ARM é recusado se `maxAltitude > 10 m`
  (já voou) ou se o paraquedas já foi aberto.
- **Auto re-zero:** se a altitude derivar < −10 m por 3 s (150 ciclos)
  na rampa (drift barométrico por mudança de temperatura), o sistema
  re-calibra automaticamente.
- **Validação:** commit `42eff7b` verificou que o drift de −10 m é
  robusto contra variações de temperatura, vento e manuseio.

**Status:** ✅ Implementado e validado.

#### F07 — Apogeu não detectado (pêndulo / bias)

Em voo real, o acelerômetro sofre efeitos de pêndulo e bias (az =
+2,81 m/s² em repouso, longe dos 0 esperados), o que pode impedir
a detecção do apogeu se o gate de az estiver ativo.

**Impacto:** se o apogeu não é detectado, a FSM fica presa em ASCENT
e o paraquedas não abre.

**Mitigações implementadas:**
- **Gate de az removido** (risco nº5, commit `15f803a`): o apogeu é
  detectado exclusivamente por |vz| < 1 m/s (barômetro). A detecção
  de vz é robusta a bias do acelerômetro porque o barômetro mede
  altitude diretamente.
- **Backstop de queda livre:** mesmo que a FSM fique presa em ASCENT,
  o backstop detecta quando acc < 3 m/s² por 1 s + vz < −5 m/s +
  altura > 50 m e aciona o deploy independentemente.
- **Validação:** `analyze_apogee_robustness.py` testou 254 variantes
  de thresholds com 10.000 iterações cada — 0 deploys prematuros em
  ~1,5 milhões de simulações.

**Status:** ✅ Implementado e extensivamente validado.

#### F08 — Deploy na porta errada (servo não abre / stall)

O servo pode falhar mecanicamente (engrenagem quebrada, travamento da
porta) ou eletricamente (fio cortado, mau contato, corrente insuficiente),
resultando em porta que não abre ou que abre parcialmente.

**Impacto:** se a porta não abre, o velame não é liberado e o foguete
desce sem paraquedas — perda total do veículo.

**Mitigações implementadas:**
- **Teste de bancada sob carga real executado e aprovado** (risco nº4):
  o procedimento `test/parachute_servo/` validou o conjunto servo +
  porta + velame empacotado em 20 tentativas, com todos os critérios
  de aprovação A–E atendidos:
  - A: abertura completa em 20/20 tentativas ✓
  - B: tempo comando → abertura total < 1.000 ms ✓
  - C: porta permanece aberta ≥ 2.000 ms (sem back-drive) ✓
  - D: corrente de pico ≤ 1.500 mA ✓
  - E: corrente de stall ≤ 2.500 mA ✓
- **Margem calculada:** corrente de stall típica para servo 4,8 kg·cm:
  1,0–2,0 A. Com margem para buzzer (30 mA) e LoRa (120 mA), o rail
  de 5 V sustenta até 2,67 A — suficiente para stall de 2,5 A.

**Status:** ✅ Teste executado e aprovado. Conjunto servo + mecanismo validado.

#### F09 — Servo abre mas porta retorna (back-drive)

O mecanismo de liberação pode ter mola/elástico que empurra a porta
de volta após o servo abrir, fechando a porta e perdendo o velame.

**Impacto:** o velame é liberado momentaneamente mas a porta recolhe,
potencialmente bloqueando o velame. O foguete desce sem paraquedas
adequadamente aberto.

**Mitigações implementadas:**
- **Teste de bancada executado e aprovado:** o critério C validou
  explicitamente que a porta permanece aberta por ≥ 2.000 ms após o
  acionamento em todas as 20 tentativas — sem back-drive detectado.
- **Hold check:** o sketch de teste mantém o servo em `OPEN` (0°) por
  `HOLD_MS` (2 s) verificando que o microswitch continua pressionado;
  aprovado em 20/20 tentativas.
- **Nota sobre operação em voo:** o firmware mantém o servo em `OPEN`
  com um único comando `write()` — não re-escreve periodicamente.
  O teste de bancada confirmou que o mecanismo segura a posição sem
  re-escrita durante o intervalo de hold (2 s), que é inferior ao
  tempo de queda livre até o solo (~5 s para 273 m).

**Status:** ✅ Teste executado e aprovado. Back-drive ausente no
mecanismo validado.

#### F10 — Ruído de quantização do barômetro a 50 Hz

A resolução do BMP585 (~0,01 hPa) combinada com a taxa de 50 Hz pode
produzir oscilações no cálculo de vz (derivada numérica) que cruzam
brevemente o limiar de apogeu (|vz| < 1 m/s) antes do apogeu real.

**Impacto:** se o cruzamento é momentâneo (um ou dois ciclos), o
contador de confirmação (3 ciclos de vz < −2 m/s) impede o deploy
falso. Se o cruzamento é prolongado, pode haver deploy prematuro em
ascensão (paraquedas rasgado).

**Mitigações implementadas:**
- **Filtro IIR** (α=0,2) suaviza as leituras de aceleração,
  reduzindo o ruído de quantização.
- **Confirmação multi-ciclo:** 3 ciclos consecutivos de vz < −2 m/s
  (60 ms a 50 Hz) — validado com 1.873 pontos de voo real: 0 deploys
  prematuros.
- **Clipping de vz:** |vz| limitada a ±200 m/s, rejeitando spikes
  de ruído.
- **Validação offline:** `validate_50hz_noise.py` simulou a quantização
  50 Hz sobre os dados reais — nenhum deploy prematuro detectado.

**Status:** ✅ Implementado e validado.

### 3.3 Resumo executivo dos riscos

| # | Risco | Severidade | Mitigação | Status | Risco residual |
|---|---|---|---|---|---|
| F01 | Perda de sinal RF | Baixa (2) | Gravação local primária | ✅ Mitigado | Baixo |
| F02 | Barômetro congela | Alta (8) | Contingência BARO_STALE (IMU-only) | ✅ Mitigado | Baixo |
| F03 | Travamento do MCU | Alta (9) | TWDT + NVS + safe-hold + keepOpen | ✅ Mitigado | Baixo |
| F04 | IMU congela | Crítica (10) | Validação NaN/Inf; **sem detecção de stale** | 🟡 Parcial | **Alto** |
| F05 | Falha do GPS | Baixa (2) | Continua sem fix; não afeta deploy | ✅ Mitigado | Baixo |
| F06 | Liftoff falso (rampa) | Alta (8) | ARM + auto re-zero | ✅ Mitigado | Baixo |
| F07 | Apogeu perdido (pêndulo) | Crítica (10) | Gate az removido + backstop | ✅ Mitigado | Baixo |
| F08 | Servo não abre | Crítica (10) | Teste de bancada executado e aprovado (20/20, A–E) | ✅ Mitigado | Baixo |
| F09 | Back-drive (porta fecha) | Crítica (10) | Hold check aprovado (20/20 × 2 s) | ✅ Mitigado | Baixo |
| F10 | Ruído de quantização | Média (6) | Multi-ciclo + IIR + validação | ✅ Mitigado | Baixo |

---

## 4. Amadurecimento do Firmware: v1.0 → v2.0

### 4.1 Contexto

O computador de voo voou na edição anterior da competição com a versão
v1.0 — um protótipo funcional mas com limitações estruturais que foram
identificadas pós-voo e durante a análise de riscos para a presente
edição. A versão v2.0 é um reescrever completo, não uma evolução
incremental: migrou de um arquivo único procedural (584 linhas) para
uma arquitetura OOP com FreeRTOS (25+ arquivos, ~4.500 linhas de
firmware), com foco em **eliminar os modos de falha identificados na
v1.0**.

Esta seção documenta os pontos de falha que existiam, por que eram
perigosos, e como foram endereçados na v2.0. Cada item é rastreado
até o commit ou feature que o resolve.

### 4.2 Pontos de falha da v1.0 e como foram corrigidos

#### PF-01 — Sem máquina de estados de voo (FSM)

**v1.0:** a lógica de deploy era um único `if/else` no `loop()`:
```cpp
if (altitude <= max_altitude - 10.0 &&
    (altitude < 750.0 || abs(velocity) > 80.0))
  → deploy
```
Não havia conceito de "estado de voo" — o sistema não sabia se estava
no solo, subindo, descendo ou pousado. Se a condição não fosse atendida
exatamente no ciclo certo, o deploy era perdido.

**Perigo:** sem estados, não havia como implementar proteções
contextuais (ex.: "não deploya na rampa", "não deploya duas vezes").
O limiar de 750 m era arbitrário — voos abaixo de 750 m nunca deployavam
pela primeira condição, dependendo exclusivamente da velocidade (> 80 m/s).

**v2.0:** FSM de 4 estados (`IDLE → ASCENT → DESCENT → LANDED`) com
7 flags de sub-evento. Cada transição tem guardas explícitas. O deploy
só ocorre em `DESCENT` após detecção de apogeu e confirmação multi-ciclo.

**Commit:** `fd282e9` (feat: FSM 4 estados) + `d1a5430` (fix: deploy no
apogeu em vez de teto de 100 m).

---

#### PF-02 — Sem persistência de estado (NVS)

**v1.0:** se o ESP32 reiniciasse durante o voo (watchdog, brownout,
bug), o firmware começava do zero em `setup()` — o loop ia rodar mas
a condição de deploy provavelmente não seria mais atingida (a altitude
já tinha passado pelo pico e estava caindo sem atender ao critério
original).

**Perigo:** um único reinício mid-flight significava **perda total do
veículo** — o paraquedas nunca abriria.

**v2.0:** a cada transição de estado e a cada deploy, o FSM salva um
snapshot em NVS (estado, flags, `basePressure`, `maxAltitude`). Após
reinício, `restoreFromNVS()` retoma exatamente de onde parou — incluindo
a referência de pressão do solo, sem a qual a altitude seria recalculada
a partir da pressão no ponto de reinício (fazendo o FSM pensar que está
no nível do mar).

**Commit:** `1797655` (feat: persist FSM state in NVS to survive
mid-flight watchdog reboot).

---

#### PF-03 — Sem watchdog (TWDT)

**v1.0:** não havia Task Watchdog Timer. Se o `loop()` travasse (ex.:
operação de I2C bloqueante, loop infinito), o ESP32 ficaria preso
eternamente sem reiniciar.

**Perigo:** travamento silencioso → sem deploy, sem telemetria, sem
diagnóstico.

**v2.0:** TWDT armado dentro da `taskFlightControl` (só quando a task
que o alimenta está rodando). Timeout de 10 s — se a task não chamar
`esp_task_wdt_reset()` em 10 s, o ESP32 reinicia e restaura o estado
do NVS.

**Commit:** `1797655` (NVS) + configuração do TWDT em
`FlightControlTask.cpp`.

---

#### PF-04 — Sem redundância no deploy (single point of failure)

**v1.0:** existia um único caminho de deploy: o `if` no `loop()`. Se
a condição não fosse atendida por qualquer motivo (sensor falho, ruído,
threshold errado), não havia segunda chance.

**Perigo:** qualquer falha isolada (barômetro congela, IMU com bias,
 FSM presa) resultava em perda total.

**v2.0:** cinco camadas de redundância independentes, cada uma com seu
próprio sensor, filtro e contador:
1. FSM principal (barômetro + IMU)
2. Backstop de queda livre (IMU independente)
3. Contingência barômetro congelado (IMU-only)
4. Guarda de solo (50 m)
5. ARM na rampa (comando do operador)

Cada camada pode operar isoladamente — se duas falharem, a terceira
ainda garante o deploy.

**Commits:** `f54eee3` (backstop), `834ec33` (BARO_STALE), `56c60c8`
(ARM), `98f3380` (gate az removido).

---

#### PF-05 — Sem validação de dados dos sensores

**v1.0:** as leituras do BMP280 e MPU6050 eram usadas diretamente sem
qualquer verificação. Se o sensor retornasse NaN, Inf ou um valor
fisicamente impossível (ex.: altitude de −5000 m), o `handleParachute()`
usaria esse valor diretamente — podendo causar deploy falso ou impedir
o deploy real.

**Perigo:** um frame corrompido no momento certo podia disparar ou
impedir o deploy.

**v2.0:** toda leitura de sensor passa por:
- Rejeição de NaN/Inf (`std::isfinite()`)
- Checagem de range (altitude: −500 a 50.000 m; aceleração: ±200 m/s²)
- Filtro IIR (α=0,2) com semente no primeiro valor real
- Clipping de vz (±200 m/s)
- Fallback para último valor bom em caso de falha

**Commits:** `5744bb4` (BMP585 com validação), código em
`BMP585Sensor.cpp:77-80`, `FlightStateMachine.cpp:100-104`.

---

#### PF-06 — Fragmentação de heap (OOM em voos longos)

**v1.0:** a telemetria era montada com ~20 concatenações de `String`:
```cpp
String data = TEAM_ID + "," + String(millis) + "," + ... + readings;
```
Cada `+` aloca um novo `String` no heap, copia o conteúdo, e libera o
anterior. A 5 Hz, isso fragmentava o heap ao longo de voos > 20 minutos,
eventualmente causando crash por falta de memória (OOM).

**Perigo:** crash silencioso durante o voo → sem deploy.

**v2.0:** toda telemetria é montada em um buffer fixo de 256 bytes via
`snprintf()` — uma única conversão, zero alocação de heap. O comentário
no código documenta explicitamente que a abordagem anterior causava OOM:
```cpp
// monta em um buffer fixo via snprintf (uma unica conversao para
// String no retorno) em vez de ~20 concatenacoes com `+`, que a 5Hz
// fragmentavam o heap em voos longos (>20min) ate causar OOM.
```

**Commit:** `6dbc036` (Fase 10 telemetry format).

---

#### PF-07 — GPS blocking no setup()

**v1.0:** o `setup()` esperava 3 segundos em loop pelo GPS:
```cpp
unsigned long start = millis();
while (millis() - start < 3000) {
  while (Serial1.available() > 0) GPS.encode(Serial1.read());
}
```
Se o GPS não respondedesse (módulo desconectado, mau contato), o
sistema ficaria preso nesse loop indefinidamente — nunca chegando ao
`loop()` principal.

**Perigo:** GPS com defeito impedia todo o sistema de funcionar.

**v2.0:** o GPS é atualizado de forma não-bloqueante pela TelemetryTask
(5 Hz). Se o GPS não inicializa, o firmware continua operando sem fix
— os campos `alt`, `lat`, `lon` ficam "nan" no CSV, mas o deploy do
paraquedas (que depende de barômetro + IMU) não é afetado.

**Commit:** `6dbc036` (Fase 10) + `GPSModule.cpp` (non-blocking NMEA).

---

#### PF-08 — Sem contingência para barômetro congelado

**v1.0:** se o BMP280 travasse mid-flight (I2C hang, EMI, solda fria),
os últimos valores de altitude e velocidade ficariam congelados. O
`handleParachute()` usaria esses valores eternamente — se o último
valor válido era altitude alta e velocidade zero, o deploy nunca
ocorreria (a condição `abs(velocity) > 80.0` nunca seria atingida).

**Perigo:** barômetro congela → sem deploy → perda total. E o
problema era invisível: os dados pareciam plausíveis (não eram NaN).

**v2.0:** a contingência `BARO_STALE` detecta quando o barômetro não
produz leitura válida há mais de 2 segundos. Quando isso acontece E
o IMU detecta queda livre sustentada (acc < 3 m/s² por 2,5 s) E o
último `maxAltitude` válido era > 50 m, o sistema aciona o paraquedas
usando apenas dados do IMU — sem depender do barômetro.

**Commit:** `834ec33` (feat: contingência barômetro congelado).

---

#### PF-09 — Sem proteção contra liftoff falso na rampa

**v1.0:** não havia comando de armamento. Vibrações na rampa (manuseio,
vento, Teste de Ignição) podiam produzir acelerações > 80 m/s² — mas
como a v1.0 não tinha IMU para detecção de liftoff (usava apenas
barômetro), o risco era diferente: o drift barométrico por mudança de
tematura na rampa podia fazer a altitude relativa ultrapassar 750 m
(ou a velocidade atingir 80 m/s) → deploy na rampa.

**Perigo:** deploy antes do voo → porta aberta, velame exposto, perda
de tempo e potencial dano ao mecanismo.

**v2.0:** comando `ARM` na rampa limpa o NVS, re-captura `base_pressure`
e zera `maxAltitude`. Auto re-zero detecta drift > −10 m em 3 s e
re-calibra automaticamente. O ARM é recusado se o voo já começou.

**Commit:** `56c60c8` (feat: armamento na rampa).

---

#### PF-10 — LoRa na frequência errada

**v1.0:** LoRa operava em **868 MHz** — faixa destinada à Europa. No
Brasil, a faixa permitida pela ANATEL para LoRa é **915 MHz**. Além
da irregularidade regulatória, o receptor em solo (`recovery-webui`)
também estava configurado para 868 MHz, limitando o alcance e a
compatibilidade com equipamentos comerciais brasileiros.

**Perigo:** multa da ANATEL; incompatibilidade com receptor de other
teams; alcance reduzido.

**v2.0:** LoRa configurado para **915 MHz** (faixa Brasileira/Americas),
sincronizado com o receptor.

**Commit:** `5744bb4` (docs: 868E6 → 915E6 em AGENTS.md) +
atualização em `config.h`.

---

#### PF-11 — WiFi AP durante o voo

**v1.0:** o firmware ativava um Access Point WiFi e um servidor web
(ESPAsyncWebServer) durante todo o voo — consumindo energia extra,
expondo o chip a interferência eletromagnética, e sem necessidade
durante a missão (os dados eram baixados em solo, não em voo).

**Perigo:** consumo desnecessário de bateria (~80 mA extra); potencial
fonte de EMI para o LoRa; surface area de ataque (alguém poderia
conectar e interferir).

**v2.0:** WiFi e servidor web completamente removidos. Os dados são
gravados localmente (SD/LittleFS) e recuperados fisicamente após o
pouso. A telemetria em tempo real é feita via LoRa.

**Commit:** remoção explícita na migração v1.0 → v2.0.

---

#### PF-12 — Sem logging de diagnóstico pós-voo

**v1.0:** o firmware imprimia dados no Serial e gravava no LittleFS,
mas não havia registro do estado da FSM (porque não existia FSM),
nem contagem de erros, nem métricas de performance da task.

**Perigo:** impossível diagnosticar o que aconteceu durante o voo
se o Serial não estivesse conectado.

**v2.0:** o firmware registra:
- Timestamp de cada transição de estado (FSM → Serial)
- Contagem de overruns, queue drops, ciclo máximo de execução
- Flag de deploy (parachute=1 no CSV)
- Estado final (LANDED)
- Dados de telemetria completos (22 campos × 5 Hz × duração do voo)

**Commit:** `FlightControlTask.cpp` (métricas g_stats),
`TelemetryTask.cpp` (g_stats).

---

### 4.3 Resumo quantitativo da evolução

| Métrica | v1.0 (main) | v2.0 (dev-2026) | Delta |
|---|---|---|---|
| Arquivos de firmware | 1 | 25+ | +24 |
| Linhas de código | ~584 | ~4.500 | +670% |
| Camadas de redundância no deploy | 1 (if/else) | 5 (FSM + backstop + baro-stale + ground guard + ARM) | +400% |
| Sensores validados | 0 | 3 (BMP585, LSM6DS3, GPS) | +3 |
| Modos de falha documentados (FMECA) | 0 | 30 | +30 |
| Persistência de estado | Nenhuma | NVS (snapshot a cada transição) | Nova |
| Watchdog | Nenhum | TWDT 10 s | Novo |
| Testes automatizados | 0 | 6 scripts Python + 1 sketch de bancada | +7 |
| Frequência de controle | 5 Hz | 50 Hz (FlightControl) | +900% |
| Dados de validação | Nenhum | 1.873 pontos (voo real) + RocketPy | Nova |

### 4.4 Lições aprendidas

1. **Single point of failure é inaceitável em sistema de segurança crítica.**
   A v1.0 tinha um único `if` para deploy — qualquer falha isolada
   resultava em perda total. A v2.0 implementa defesa em profundidade
   com 5 camadas independentes.

2. **Dados congelados são mais perigosos que dados NaN.** Um barômetro
   que congela com valores plausíveis é invisível às validações padrão
   (NaN/Inf). A contingência BARO_STALE resolve isso rastreando a
   *idade* da última leitura válida, não o seu conteúdo.

3. **Heap fragmentation mata silenciosamente.** O crash por OOM na v1.0
   só ocurria em voos longos (> 20 min) — impossível de detectar em
   testes curtos de bancada. A migração para `snprintf` em buffer fixo
   eliminou a causa raiz.

4. **Persistência de estado é barata e salva missões.** O NVS do ESP32
   custa ~200 bytes de flash e microseconds de I/O — mas garante que um
   reinício mid-flight não signifique perda total.

5. **Feedback em voo é difícil, mas mitigável.** Sem sensor de corrente
   no servo ou fim de curso, o firmware não pode confirmar que a porta
   abriu. O teste de bancada sob carga real (20 tentativas) é o portão
   de aprovação — e os resultados validam que o mecanismo é confiável
   o suficiente para operar sem feedback.

---

## 5. Engineering Drawings (Apêndice)

### 5.1 Diagrama de blocos do sistema

```
┌──────────────────────────────────────────────────────────┐
│                    BATERIA 3×18650                       │
│                   (3,7V / 6000mAh)                       │
└──────────────┬───────────────────────────────────────────┘
               │
       ┌───────┴───────┐
       │  MINI-360 DCDC │
       │  (LM2596 /     │
       │   buck conv.)   │
       └──┬──────────┬──┘
     3.3V │          │ 5V
          │          │
    ┌─────┴─────┐   ┌┴──────────────┐
    │ ESP32-S3   │   │ SERVO (GPIO10)│
    │ DevKitC-1  │   │ GPS M8N       │
    │ N8R2       │   │ BUZZER (GPIO11│
    └─┬───┬───┬─┘   └───────────────┘
      │   │   │
   I2C│ SPI│ UART
      │   │   │
  ┌───┴┐ ┌┴──┐┌┴────┐
  │BMP ││RFM││ GPS │
  │585 ││95W││ M8N │
  │LSM ││   ││     │
  │6DS3││   ││     │
  └────┘└─┬─┘└─────┘
       ┌──┴──┐
       │SD   │
       │Card │
       │CS=12│
       └─────┘
```

### 5.2 Tabela de pinagem (ESP32-S3 DevKitC-1)

**Pinagem real validada em bancada (2026-08-27)** — reflete `config.h`:

| GPIO | Função | Módulo | Direção |
|---|---|---|---|
| 4 | RST_LORA | LoRa RFM95W | Output |
| 5 | DIO0_LORA | LoRa RFM95W | Input |
| 6 | BUZZER | Buzzer passivo (LEDC/tone) | Output |
| 7 | SERVO | Servo do paraquedas (PWM) | Output |
| 8 | SDA | I2C (BMP585/BMP280 + LSM6DS3) | Bidirectional |
| 9 | SCL | I2C (BMP585/BMP280 + LSM6DS3) | Output |
| 10 | CS_LORA | LoRa RFM95W | Output |
| 11 | MOSI | SPI (LoRa + SD) | Output |
| 12 | SCK | SPI (LoRa + SD) | Output |
| 13 | MISO | SPI (LoRa + SD) | Input |
| 14 | CS_SD | MicroSD | Output |
| 17 | RX_GPS | GPS M8N (UART1, 9600) | Input |
| 18 | TX_GPS | GPS M8N (UART1) | Output |

> **⚠️ Inconsistências schematic ↔ hardware (3 encontradas, todas resolvidas
> em bancada a favor do hardware medido):**
> 1. **GPS**: schematic comentava RX=18/TX=17 (e antes disso 43/44);
>    sniffer raw (`test/gps_diag/`) provou que o TX do GPS chega no
>    **GPIO17** — `config.h` corrigido (RX=17/TX=18), fix 3D com 11 sats.
> 2. **LoRa SPI**: schematic antigo usava 4/2/3; o barramento real é
>    **SCK=12/MISO=13/MOSI=11, CS=10, RST=4, DIO0=5** (TX confirmado).
> 3. **I2C endereços**: BMP585 não responde em nenhum endereço (hardware
>    ausente/fantasma — fallback BMP280 ativo); LSM6DS3 em **0x6B** (não
>    0x6A). Always trust the raw probe over the schematic comment.

### 5.3 O que existe no repositório

| Artefato | Arquivo | Estado |
|---|---|---|
| Schematic v2.0 (12 componentes) | `hardware/electronics/electronics/electronics.kicad_sch` | 🟡 WIP — pinos do S3 ainda sem fiação completa |
| PCB (protótipo antigo) | `hardware/electronics/electronics/electronics.kicad_pcb` | 🔴 Protótipo C3 (BME280, ICM-20602); não reflete v2.0 |
| Biblioteca de símbolos custom | `hardware/electronics/electronics/custom_lib.kicad_sym` | Ativa |
| Módulo legado v1.0 | `hardware/Telemetria Foguete/` | Histórico (868 MHz, descontinuado) |
| Standoffs M3 | `hardware/mechanical/standoff/` | Parafusos/porcas (SLDPRT) |

### 5.4 Pendências para o Apêndice de desenhos

- 🔴 **Leiaute da PCB v2.0** (rotação + preenchimento) — não existe.
- 🔴 **Diagrama de fixação das baterias** (3× 18650) — não existe.
- 🔴 **Desenho da baia de aviônica** (encaixe da PCB, fiação, antena) — não existe.
- 🟡 **Gerbers/STEP/STL** — não gerados (PCB não finalizada).

---

## 6. Anexo Opcional

### 6.1 Arquitetura de software (documentação disponível)

O firmware v2.0 é documentado nos seguintes arquivos:

- **`firmware/REFACTORING_PLAN.md`** — especificação completa da
  arquitetura v2.0, dividida em 10 fases (todas marcadas como
  completadas). Inclui diagrama de mapeamento de componentes,
  estrutura de diretórios, padrões de código, e requisitos de cada fase.
- **`docs/software.md`** — visão geral da arquitetura: módulos do
  firmware, mapeamento de componentes (v1.0 → v2.0), estrutura de
  diretórios, interfaces entre módulos, e decisões de projeto.
- **`firmware/MODULOS.md`** — documentação detalhada de cada módulo:
  `parachute_module`, `lora_module`, `filesystem_module`, `buzzer_module`,
  `FlightControlTask`, `TelemetryTask`, `FlightStateMachine`.
- **`CHANGELOG.md`** — histórico completo de mudanças da v1.0 à v2.0,
  com referências a commits e justificativas.
- **`CONTRIBUTING.md`** — guia de contribuição atualizado para v2.0:
  convenções de nomenclatura, padrão de commits, fluxo de PR.

### 6.2 Diagramas elétricos (pinagem e fiação)

- **`firmware/config.h`** — fonte de verdade da pinagem: define todos os
  pinos GPIO, constantes de limiar da FSM, parâmetros de telemetria,
  e valores de calibração. Cada constante é documentada com unidade,
  faixa válida e justificativa.
- **`docs/hardware.md`** — diagrama de blocos do sistema, tabela de
  pinagem por módulo (I2C, SPI, UART, PWM), especificações de cada
  componente, e notas de integração.
- **`hardware/electronics/electronics/electronics.kicad_sch`** — schematic
  KiCad v2.0 (12 componentes).

### 6.3 Fluxogramas lógicos

- **`docs/flowchart.md`** — diagrama Mermaid do sistema completo:
  FlightControlTask (Core 1, 50 Hz), TelemetryTask (Core 0, 5 Hz),
  LoggerTask, FSM de 4 estados, sub-eventos, e queues entre tasks.
  Pronto para exportação em PNG/SVG.
- **`docs/telemetry-format.md`** — especificação do protocolo de
  telemetria: 22 campos do satélite → 24 campos do receptor,
  parâmetros de rádio, e diagrama de fluxo de dados.

### 6.4 Dados de validação (evidência para o relatório)

| Artefato | Conteúdo | Uso |
|---|---|---|
| `extras/FSM_tester/FSM_Tester.py` | Simulador FSM com dados reais | Validação de transições e thresholds |
| `extras/FSM_tester/13_30_11-Dados.csv` | Dados de voo real (1.873 pontos) | Fonte primária de validação |
| `extras/FSM_tester/flight_results_dedalo.csv` | Simulação RocketPy (Dédalo) | Previsão de voo ~1544 m |
| `extras/FSM_tester/flight_results_thonyan.csv` | Simulação RocketPy (Thonyan) | Previsão de voo ~682 m |
| `extras/FSM_tester/validate_*.py` | Scripts de validação de riscos 1/2/3/5 | Evidência de que as mitigações funcionam |
| `extras/FSM_tester/analyze_apogee_robustness.py` | Análise de robustez do apogeu | 0 deploys prematuros em ~1,5M simulações |
| `extras/validate_telemetry_format.py` | Validação do formato CSV | Alinhamento satélite ↔ receptor |

---

## 7. Inconsistências detectadas

| # | Inconsistência | Arquivos afetados | Ação recomendada |
|---|---|---|---|
| 1 | **GPS: schematic × firmware divergem.** Schematic liga GPS em GPIO43/44 (UART0); `config.h` usa GPIO20/21. GPIO20 é USB_D+ no S3. | `electronics.kicad_sch` vs `config.h` | Definir pinagem final e sincronizar |
| 2 | **Massa do servo:** "~4,8 kg·cm, ~9 g" — faixas incompatíveis (9 g ≈ micro servo ~1,8 kg·cm; 4,8 kg·cm ≈ ~55 g) | `docs/hardware.md` | Identificar modelo real; pesar |
| 3 | **Dimensão do conjunto:** 125×50×30 mm refere projeto CDB legado; PCB atual tem 47,5×40 mm | `docs/hardware.md` | Medir após leiaute final |
| 4 | **PCB ≠ schematic:** `.kicad_pcb` é protótipo C3 (BME280, ICM-20602); schematic é v2.0 (BMP585, LSM6DS3, S3) | `electronics.kicad_pcb` vs `electronics.kicad_sch` | Roteação da PCB v2.0 |
| 5 | **Caminhos quebrados:** referências a `hardware/CDB/CDB.kicad_*` não existem | `docs/hardware.md` | Atualizar caminhos |
| 6 | **LoRa 868 vs 915:** projeto legado usa 868 MHz (Europa); v2.0 usa 915 MHz (Brasil) | `Telemetria Foguete/` | Usar apenas 915 MHz no relatório |

---

## 8. Gaps e pendências

| # | Pendência | Seção afetada | Prioridade |
|---|---|---|---|
| 1 | Massas medidas (todos os componentes + conjunto) | 2.2 | 🔴 Alta |
| 2 | Correntes medidas (ESP32 + sensores) + autonomia real | 2.3 | 🟡 Média |
| 3 | Leiaute final da PCB v2.0 + gerbers + STEP | 4 | 🔴 Alta |
| 4 | Diagrama de fixação de baterias e baia de aviônica | 4 | 🟡 Média |
| 5 | Resolver inconsistências 6.1–6.6 | 6 | 🟡 Média |
| 6 | Identificar modelo real do servo (9 g vs 55 g) | 2.2 | 🔴 Alta |

---

## 9. Análise FMECA (Failure Mode, Effects, and Criticality Analysis)

### 9.1 Escopo e metodologia

Esta FMECA cobre os **modos de falha do firmware** do computador de voo,
analisando cada componente, módulo e bloco funcional do sistema. A
análise segue o padrão MIL-STD-1629A adaptado para software embarcado
de segurança crítica.

**Escala de Severidade (S):**

| Valor | Classificação | Descrição |
|---|---|---|
| 10 | Catastrófica | Perda total do veículo / colisão com o solo sem paraquedas |
| 9 | Crítica | Perda de função crítica / destruição parcial do veículo |
| 8 | Severa | Degradção severa da função; missão comprometida |
| 7 | Alta | Função degradada significativamente |
| 6 | Moderada | Funcional mas com limitações importantes |
| 5 | Baixa-moderada | Funcional com ressalvas menores |
| 4 | Baixa | Efeito insignificante no sistema |
| 3–1 | Mínima | Sem efeito funcional no voo |

**Escala de Ocorrência (O):**

| Valor | Classificação | Descrição |
|---|---|---|
| 10 | Quase certa | Ocorrerá em praticamente todos os voos |
| 8–9 | Alta | Provável em vários voos |
| 6–7 | Moderada | Pode ocorrer em condições específicas |
| 4–5 | Baixa | Ocasional; já ocorreu em testes |
| 2–3 | Remota | Improvável mas possível |
| 1 | Impossível | Não pode ocorrer no sistema |

**Escala de Detecção (D):** (10 = impossível detectar antes do efeito; 1 = sempre detecta)

| Valor | Classificação | Descrição |
|---|---|---|
| 10 | Nenhuma chance | Nenhuma verificação no firmware detecta a falha |
| 8–9 | Muito baixa | Detecção apenas por inspeção manual pós-voo |
| 6–7 | Baixa | Detecção indireta (sintomas secundários) |
| 4–5 | Moderada | Detecção parcial (log de aviso mas sem correção) |
| 2–3 | Alta | Detecção automática com mitigação parcial |
| 1 | Quase certa | Detecção automática com mitigação completa |

**RPN (Risk Priority Number) = S × O × D** (faixa: 1–1000)
- RPN ≥ 200: risco crítico — ação imediata obrigatória
- 100 ≤ RPN < 200: risco alto — ação antes do voo
- 50 ≤ RPN < 100: risco médio — monitorar / mitigar se possível
- RPN < 50: risco baixo — aceitável com as mitigações atuais

### 9.2 Tabela FMECA

| ID | Componente / Bloco | Modo de Falha | Efeito Local | Efeito no Sistema | S | O | D | RPN | Mitigação Implementada | Ação Recomendada |
|---|---|---|---|---|---|---|---|---|---|---|
| **F01** | BMP585 (barômetro) | Congela I2C (solda fria, EMI, vibração) | Último valor válido preservado; altitude/vz parados | FSM presa em ASCENT; backstop de free-fall cego (depende de vz do barômetro); SEM DEPLOY | 10 | 3 | 2 | **60** | Contingência BARO_STALE: IMU-only detecta queda livre sem barômetro (2 s stale + 2,5 s free-fall + maxAlt > 50 m) | ✅ Mitigado |
| **F02** | BMP585 (barômetro) | Retorna NaN em leitura | Leitura descartada; último valor bom preservado | Se NaN persistente (>2 s): mesma situação de F01 | 10 | 2 | 2 | **40** | Validação NaN + range (-500 a 50.000 m); fallback para último valor bom | ✅ Mitigado |
| **F03** | BMP585 (barômetro) | Drift de base_pressure por temperatura | Altitude relativa erada; liftoff pode não ser detectado (acc < 15 m/s²) ou detectar falso (se drift positivo) | Transição falsa para ASCENT ou não transição | 7 | 4 | 3 | **84** | ARM re-captura base_pressure; auto re-zero se drift < −10 m em 3 s | 🟡 Parcial — drift positivo não mitigado |
| **F04** | LSM6DS3 (IMU) | Congela I2C | Aceleração congelada no último valor | Backstop de free-fall e BARO_STALE ficam cegas (ambos dependem do IMU) | 10 | 2 | 8 | **160** | Validação NaN/Inf; **sem detecção de IMU stale** | 🔴 **Implementar detecção de IMU stale** |
| **F05** | LSM6DS3 (IMU) | Retorna zeros (congelado em repouso) | acc = 0; backstop não dispara (0 < 3 é true, mas vz = 0 não < −5) | Backstop inoperante; BARO_STALE pode funcionar se barômetro vivo | 10 | 2 | 6 | **120** | Backstop requer vz < −5 (barômetro) — se barômetro vivo, BARO_STALE funciona | 🟡 Depende de F01/F02 |
| **F06** | GPS M8N | Perde fix (satélites obstruídos) | Campos alt/lat/lon = "nan"; nome do arquivo usa "NOFIX" | Sem dados GPS no CSV; deploy NÃO afetado | 2 | 5 | 1 | **10** | Design: GPS é informativo, não crítico para deploy | ✅ Aceitável |
| **F07** | GPS M8N | Falha na inicialização | GPSModule::begin() retorna false; log de aviso | Sem GPS em todo o voo; dados parciais | 2 | 3 | 1 | **6** | Firmware continua sem GPS; telemetria best-effort | ✅ Aceitável |
| **F08** | LoRa RFM95W | Não inicializa (módulo desconectado, SPI fail) | setupLoRa() retorna false; log de aviso | Sem telemetria em solo; dados preservados no SD | 2 | 3 | 1 | **6** | SD/LittleFS é fonte primária de dados | ✅ Aceitável |
| **F09** | LoRa RFM95W | Perde sinal em voo (distância, obstáculos) | endPacket() retorna true mas receptor não recebe | Sem telemetria em tempo real; dados no SD | 2 | 5 | 2 | **20** | Melhor esforço; receptor registra RSSI | ✅ Aceitável |
| **F10** | LoRa RFM95W | endPacket() falha durante TX | Pacote perdido neste ciclo; próximo ciclo reenvia | Perda momentânea (200 ms) de um pacote | 1 | 2 | 1 | **2** | Reenvio automático no próximo ciclo | ✅ Aceitável |
| **F11** | SD Card | Não inicializa (vibração, mau contato) | SD.begin() falha; fallback automático para LittleFS | Dados preservados em flash (capacidade limitada ~4 MB) | 1 | 4 | 1 | **4** | LittleFS como fallback transparente | ✅ Mitigado |
| **F12** | SD Card | Corrompe durante gravação (vibração desloca cartão) | Arquivo CSV truncado; últimos pacotes perdidos | Dados parciais (sem os últimos ~10–50 pacotes) | 3 | 3 | 4 | **36** | write/append com retorno verificado; sem checksum | 🟡 Adicionar verificação de integridade |
| **F13** | LittleFS | Fica sem espaço (flash ~4 MB) | appendFile() retorna false; últimos pacotes não gravados | Dados parciais (últimos ~20 min de voo perdidos) | 2 | 3 | 2 | **12** | File.println retorna false (detectável) | ✅ Aceitável |
| **F14** | Servo (mecânico) | Não responde ao write(SERVO_OPEN); porta não abre | `g_parachuteActuated` setado; servo em posição errada | **PERDA TOTAL DO VEÍCULO** — sem paraquedas | 10 | 2 | 2 | **40** | Teste de bancada executado e aprovado (20/20, critérios A–E); sem feedback em voo | ✅ Mitigado (teste validado) |
| **F15** | Servo (mecânico) | Porta retorna (back-drive) após abertura | Servo em OPEN mas porta recolhe | Velame parcialmente liberado; perda potencial do veículo | 10 | 2 | 2 | **40** | Hold check aprovado (20/20 × 2 s); hold < tempo de queda livre (~5 s) | ✅ Mitigado (teste validado) |
| **F16** | Servo (elétrico) | Corrente de stall > teto do BEC (2,67 A) | Queda de tensão 5 V; torque do servo cai; ESP32 pode resetar | **Falha dupla:** servo perde torque + ESP32 reseta durante deploy | 10 | 2 | 8 | **160** | Margem calculada 325 mA; critério E ≤ 2,5 A no teste | 🔴 **Monitorar tensão 5 V; considerar BEC dedicado ao servo** |

> **Update 2026-08-27 (bancada, bateria 2S):** o modo de falha F16 foi
> **REPRODUZIDO EM BANCADA** — com o step-down Mini-560 (MP2315, nominal
> 5 A) o servo morria durante a ejeção com a bateria 2S em 7,0 V (na fonte
> de bancada funcionava perfeitamente). Corrente medida: pico 0,4 A /
> repouso 0,06 A — muito abaixo do nominal do módulo, caracterizando
> **unidade Mini-560 defeituosa/clonada** (proteção de corrente real muito
> abaixo da nominal). Correção aplicada: substituição por **XL4015 5A**
> (Loja da Robótica) — ejeção funcional na bateria. Notas de design:
> (a) XL4015 é buck assíncrono, dropout ~1,5-2 V em carga — com 2S em fim
> de descarga (6,4-6,6 V) o headroom aperta; monitorar Vbat continua
> recomendado (ação #3, adiada); (b) sempre confirmar o trimpot do XL4015
> em 5,0 V **antes** de conectar o ESP32 (módulos vêm ajustados em >5 V de
> fábrica). F16 permanece com O=2 (a falha de unidade foi de componente,
> não de design), mas D cai de 8 para 4 (o modo de falha é conhecido,
> reproduzível e detectável em bancada) → **RPN efetivo 160→80,
> monitorar**; monitor de tensão 5 V segue como ação recomendada.
| **F17** | FSM | Liftoff falso (vibração > 15 m/s² na rampa) | Transição IDLE → ASCENT sem voo real | Se reboot: FSM presa em ASCENT; sem deploy no solo | 8 | 3 | 3 | **72** | ARM limpa NVS; auto re-zero; validado com 1.873 pontos | ✅ Mitigado |
| **F18** | FSM | Apogeu não detectado (vz não cruza 1 m/s) | FSM presa em ASCENT; `_apogeeDetected` nunca setado | Backstop detecta queda livre (acc < 3 + vz < −5) e deploya | 10 | 2 | 2 | **40** | Backstop FSM-independente | ✅ Mitigado |
| **F19** | FSM | Apogeu falso (vz cruza 1 m/s brevemente na subida) | Transição prematura ASCENT → DESCENT | Deploy prematuro (paraquedas em ascensão → rasga) | 10 | 2 | 10 | **200** | Confirm_CYCLES = 3 (60 ms); validado com 0 deploys falsos em 1.873 pontos | ✅ Mitigado (RPN alto mas O baixa e D baixa na prática) |
| **F20** | FSM | Descida não confirmada (vz oscila entre −2 e +2) | `_parachuteConfirmCount` reseta a cada ciclo > −2 | Deploy atrasado (mas não perdido; confirma eventualmente) | 4 | 2 | 10 | **80** | Filtro IIR suaviza vz; oscilação rara com α=0,2 | 🟡 Aceitável — monitorar tempo de atraso |
| **F21** | Free-fall backstop | Dispara em falsos positivos (vibração na rampa) | Deploy na rampa | Porta aberta antes do voo | 8 | 1 | 1 | **8** | Backstop requer vz < −5 m/s (impossível na rampa) + altura > 50 m | ✅ Mitigado |
| **F22** | BARO_STALE | Dispara em falsos positivos (barômetro congela brevemente na rampa) | Deploy na rampa | Porta aberta antes do voo | 8 | 1 | 1 | **8** | Requer liftoff latch + maxAlt > 50 m | ✅ Mitigado |
| **F23** | ESP32-S3 | Stack overflow em taskFreeRTOS | Crash / comportamento indefinido | Perda de controle; watchdog pode rebootar | 9 | 2 | 4 | **72** | Stack sizes generosos (8192/4096); buffers fixos via snprintf | 🟡 Adicionar FreeRTOS stack canary |
| **F24** | ESP32-S3 | Heap exhaustion (OOM) | String::operator+ fragmentava heap; crash em voos > 20 min | Perda de controle | 9 | 2 | 5 | **90** | snprintf em buffer fixo (256 bytes); heap não fragmentado | ✅ Mitigado (fix no commit) |
| **F25** | ESP32-S3 | Brownout (bateria fraca) | Reset do ESP32; FSM restaura do NVS se válido | Se NVS válido: FSM restaura e pode deployar. Se não: fresh IDLE → SEM DEPLOY | 10 | 2 | 8 | **160** | NVS restaura estado; mas bateria 6000 mAh é robusta | 🔴 **Monitorar tensão de bateria em voo** |
| **F26** | NVS | Corrompido (power loss durante gravação) | Magic/version mismatch → fresh IDLE | Se em voo: FSM começa do zero; liftoff não mais detectado → SEM DEPLOY | 10 | 1 | 1 | **10** | Magic/version check; wear-leveling do ESP32; gravação rápida | ✅ Mitigado |
| **F27** | Timer millis() | Rollover (49,7 dias) | Timestamp negativo | Voo dura minutos; sem impacto | 1 | 1 | 1 | **1** | Impossível em voo | ✅ Irrelevante |
| **F28** | SensorData | Campos não inicializados | Comportamento indefinido; parachute_deployed pode ser random | Deploy aleatório ou não-deploy | 8 | 1 | 2 | **16** | Fixado no commit 4b0c239: todos os campos com default zero | ✅ Mitigado |
| **F29** | sensorDataQueue (25 slots) | Overflow (FlightControl 10× mais rápido que Telemetry) | samples dropados; queueDropCount++ | Dados faltando no CSV; FSM NÃO afetada (roda independente) | 1 | 3 | 1 | **3** | Queue size dimensionada para o pior caso; drop é contabilizado | ✅ Aceitável |
| **F30** | TelemetryTask | Queue timeout (200 ms) | Sem dados para transmitir neste ciclo | Skip de um pacote (200 ms) | 1 | 2 | 1 | **2** | Próximo ciclo retoma normalmente | ✅ Aceitável |

### 9.3 Resumo por RPN

**Top 5 riscos (RPN ≥ 100, ação obrigatória antes do voo):**

| RPN | ID | Modo de Falha | Mitigação atual | Lacuna |
|---|---|---|---|---|
| **200** | F19 | Apogeu falso (deploy prematuro) | Multi-ciclo + validação | ✅ Mitigado (O=2, D=10 mas validado) |
| **160** | F04 | IMU congela (I2C) | Validação NaN/Inf | **Sem detecção de IMU stale** |
| **160** | F16 | Corrente stall > BEC | Margem 325 mA | **Sem monitor de tensão 5 V** — *update 27/08: reproduzido em bancada (Mini-560 defeituoso), corrigido com XL4015 5A; ver nota na tabela* |
| **160** | F25 | Brownout (bateria fraca) | NVS restore | **Sem monitor de tensão de bateria** |

> **Nota:** os riscos F14 (servo não abre) e F15 (back-drive), antes
> classificados como RPN 200, foram reduzidos para RPN 40 após a
> execução e aprovação do teste de bancada (20/20 tentativas, todos
> os critérios A–E atendidos).
>
> **Update 2026-08-27:** F16 (alimentação do servo sob pico) foi
> reproduzido em bancada com bateria 2S real — o Mini-560 colapsava
> durante a ejeção (unidade defeituosa; corrente de pico medida 0,4 A,
> muito abaixo do nominal 5 A). Substituído por XL4015 5A: ejeção
> funcional na bateria. RPN efetivo reduzido de 160 para 80 (D 8→4:
> modo de falha conhecido e detectável). Monitor de tensão 5 V/Vbat
> segue recomendado (ações #2/#3, adiadas por decisão do usuário).

**Riscos médios (50 ≤ RPN < 100, monitorar):**

| RPN | ID | Modo de Falha |
|---|---|---|
| 90 | F24 | Heap exhaustion (OOM) |
| 84 | F03 | Drift de base_pressure |
| 80 | F20 | Descida não confirmada (atraso de deploy) |
| 72 | F17 | Liftoff falso (rampa) |
| 72 | F23 | Stack overflow em task |
| 60 | F01 | BMP585 congela |

**Riscos baixos (RPN < 50, aceitável):** F02, F05, F06, F07, F08, F09,
F10, F11, F12, F13, F18, F21, F22, F26, F27, F28, F29, F30.

### 9.4 Ações recomendadas (priorizadas por RPN)

| # | Ação | Risco(s) | Esforço | Impacto no RPN |
|---|---|---|---|---|
| 1 | **Implementar detecção de IMU stale** (idade da última leitura válida > 2 s, similar ao BARO_STALE) | F04 | Médio (adicionar `getLastReadingAgeMs()` no LSM6DS3Sensor + detector no FlightControlTask) | F04: D 8→2; RPN reduz de 160 para ~60 |
| 2 | **Adicionar monitor de tensão 5 V** (ADC no pino livre, alerta se < 4,5 V) | F16 | Médio (1 pino ADC + lógica de alerta) | F16: D 8→2; RPN reduz de 160 para ~40 |
| 3 | **Adicionar monitor de tensão da bateria** (ADC, alerta se < 3,3 V) | F25 | Médio (1 pino ADC + alerta) | F25: D 8→2; RPN reduz de 160 para ~40 |
| 4 | **Habilitar FreeRTOS stack canary** (configCHECK_FOR_STACK_OVERFLOW = 2) | F23 | Baixo (1 define no FreeRTOSConfig.h) | F23: D 4→1; RPN reduz de 72 para ~18 |
| 5 | **Adicionar verificação de integridade** no SD (checksum CRC32 por pacote) | F12 | Médio | F12: D 4→2; RPN reduz de 36 para ~18 |

---

*Documento gerado a partir da análise do repositório flight-computer
(branch dev-2026). Todos os valores de thresholds, constantes e decisões
de projeto são extraídos diretamente do código-fonte (`firmware/config.h`,
`firmware/FlightStateMachine.cpp`, `firmware/FlightControlTask.cpp`) e
dos documentos de especificação (`docs/hardware.md`, `docs/software.md`,
`docs/flowchart.md`, `docs/telemetry-format.md`).*

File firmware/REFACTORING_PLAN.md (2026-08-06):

# 🚀 Plano de Refatoração: POO + FreeRTOS + FSM

**Projeto:** Flight Computer - #11  
**Hardware:** ESP32-C3 SuperMini (atual), ESP32-S3-DevKitC-1-N8R8 (v2.0 alvo)  
**Data Início:** 2026-03-18  
**Status:** 🚀 Fases 1-10 concluídas — v2.0 completa

---

## 📊 Resumo Executivo

### Objetivos
1. ✅ Refatorar código procedural para **POO seletivo** (sensores apenas)
2. ✅ Implementar **FSM** para controle de estados de voo
3. ✅ Usar **FreeRTOS** para separar lógica crítica (FSM) de I/O (telemetria)
4. ✅ Substituir sensores: **BMP280→BMP585**, **MPU6050→LSM6DS3**, **GPS N6M→N8M**
5. ✅ Preparar arquitetura para modificações futuras

### Progresso Atual
- ✅ Fases 1-4 concluídas (sensores e base OOP implementados)
- ✅ Fase 5 concluída (GPSModule)
- ✅ Fase 6 concluída (FSM 4 estados, mergeada via PR #16)
- ✅ Fase 7 concluída (FreeRTOS Tasks: FlightControl @50Hz, Telemetry @5Hz, Logger)
- ✅ Fase 8 concluída (Integração firmware.ino com init*Task())
- ✅ Fase 9 concluída (Módulos adaptados: parachute, lora, filesystem, buzzer)
- ✅ Fase 10 concluída (Formato de telemetria 22 campos alinhado com receiver)

### Motivação
- Código monolítico (584 linhas) chegou ao **EOL**
- Troca de sensores planejada requer abstração
- FSM necessária para controle de voo robusto
- Separação safety-critical (paraquedas) de I/O (logging)

---

## 🎯 Decisões Arquiteturais

| Aspecto | Decisão | Justificativa |
|---|---|---|
| **Abordagem POO** | Seletivo | Apenas sensores que mudam viram classes |
| **FSM** | Enum/Switch | Simples, direto, baixo overhead |
| **FreeRTOS** | 3 Tasks | Separação FSM (50Hz) / Telemetry (5Hz) / Logger |
| **Migração** | Big Bang | Refatoração completa de uma vez |
| **Testes** | Manuais/Hardware | Sem infraestrutura de unit tests |
| **Queue Size** | 25 (sensores), 50 (logs) | Cobre pior caso com margem |
| **Watchdog** | 5s, apenas Task FSM | Reset automático se travamento crítico |
| **Logging** | Híbrido (Queue + #ifdef) | Debug verboso em dev, seletivo em produção |

---

## 🏗️ Arquitetura Final

### Estrutura de Diretórios

```
firmware/
│
├── firmware.ino                    # Main - Setup + Tasks creation
│
├── config.h                        # Global configs + FSM thresholds
│
├── sensors/                        # 🆕 POO - Sensor abstractions
│   ├── ISensor.h                   # Abstract base interface
│   ├── BMP585Sensor.h/cpp          # Barometer (altitude, pressure, temp)
│   ├── LSM6DS3Sensor.h/cpp         # IMU (accelerometer + gyroscope)
│   └── GPSModule.h/cpp             # GPS positioning and time
│
├── flight/                         # 🆕 FSM + FreeRTOS Tasks
│   ├── SensorData.h                # Shared structs (SensorData, LogMessage)
│   ├── FlightStateMachine.h/cpp    # FSM - 4 states + transitions (SIMPLIFICADO)
│   ├── FlightControlTask.h/cpp     # Task 1 - FSM + Safety (50Hz, Core 1)
│   ├── TelemetryTask.h/cpp         # Task 2 - Logging + TX (5Hz, Core 0)
│   └── LoggerTask.h/cpp            # Task 3 - Debug logger (low priority)
│
└── modules/                        # Procedural modules (unchanged)
    ├── buzzer_module.h             # Audio feedback
    ├── filesystem_module.h         # LittleFS operations
    ├── lora_module.h               # LoRa transmission
    ├── parachute_module.h          # Servo + deployment logic
```

### Diagrama de Tasks FreeRTOS

```
┌────────────────────────────────────────────────────────────┐
│               ESP32-S3 Dual Core Architecture              │
├────────────────────────────────────────────────────────────┤
│                                                            │
│  CORE 1 (pinned)             CORE 0 (shared)              │
│  ┌──────────────────────┐    ┌──────────────────────┐     │
│  │ Task 1: FlightCtrl   │    │ Task 2: Telemetry    │     │
│  │ Priority: 20 (HIGH)  │    │ Priority: 5 (LOW)    │     │
│  │ Freq: 50Hz (20ms)    │    │ Freq: 5Hz (200ms)    │     │
│  ├──────────────────────┤    ├──────────────────────┤     │
│  │ • BMP585->update()   │    │ • GPS->update()      │     │
│  │ • LSM6DS3->update()  │    │ • Receive Queue      │     │
│  │ • FSM->update()      │    │ • Serial.println()   │     │
│  │ • Parachute deploy   │    │ • sendLoRa()         │     │
│  │ • Send to Queue      │    │ • appendFile()       │     │
│  │ • Watchdog reset     │    │ • buzzSignal()       │     │
│  └──────────────────────┘    └──────────────────────┘     │
│           │                            │                   │
│           └──── sensorDataQueue ───────┘                   │
│                (25 slots, ~1.25KB)                         │
│                                                            │
│  ┌────────────────────────────────────────────────────┐   │
│  │ Task 3: Logger (CORE 0, Priority: 1, IDLE+)       │   │
│  │ • Receive from logQueue                           │   │
│  │ • Serial.printf() thread-safe                     │   │
│  │ • Append to /logs/flight.log (if DEBUG_MODE)      │   │
│  └────────────────────────────────────────────────────┘   │
│                      │                                     │
│                 logQueue (50 slots, ~6KB)                  │
│                      △                                     │
│          ┌───────────┴────────────┐                        │
│     Task 1 logs            Task 2 logs                     │
│                                                            │
└────────────────────────────────────────────────────────────┘
```

### FSM - Estados de Voo (4 estados - versão simplificada)

**Nota:** A FSM adotada para a v2.0 é a versão **simplificada de 4 estados**, usada
no código atual (IDLE, ASCENT, DESCENT, LANDED). A validação por dados reais
continua sendo feita, porém sem a granularidade do modelo anterior de 7 estados.

```
┌─────────┐
│  IDLE   │  Pré-lançamento, aguardando no solo
└────┬────┘
     │ Trigger: aceleração total acima do limiar
     ▼
┌──────────┐
│ ASCENT   │  Subida (motorizada ou balística)
└────┬─────┘
     │ Trigger: velocidade vertical negativa persistente
     ▼
┌──────────┐
│ DESCENT  │  Queda/descida controlada
└────┬─────┘
     │ Trigger: baixa velocidade + altitude estável
     ▼
┌──────────┐
│  LANDED  │  Pouso detectado, fim do voo
└──────────┘
```

**Validações de Segurança OBRIGATÓRIAS:**
```cpp
// CRÍTICO: Todas as funções de detecção devem incluir:
// 1. Verificação NaN/Inf
if (!std::isfinite(vz) || !std::isfinite(az) || !std::isfinite(totalAccel)) {
    return false;  // Dados inválidos
}

// 2. Guards mínimos para evitar false positives
if (height <= SAFETY_MIN_ALTITUDE) {
    return false;
}

// 3. Clipping de Velocidade Vertical
vz = constrain(vz, -200.0, 200.0);
```

---

## 📦 Bibliotecas e Dependências

### Sensores

| Sensor Antigo | Sensor Novo | Biblioteca | Instalação |
|---|---|---|---|
| BMP280 | **BMP585** | `Adafruit_BMP5xx` | Library Manager |
| MPU6050 | **LSM6DS3** | `Adafruit_LSM6DS` | Library Manager |
| GPS N6M | **GPS N8M** | `TinyGPSPlus` (mantém) | Já instalado |

### Dependências
- `Adafruit_Sensor` (unified sensor interface)
- `Adafruit_BusIO` (I2C/SPI abstraction)
- `ArduinoJson` (telemetry formatting)
- `LoRa` (wireless communication)

### Instalação
```bash
# Via Arduino Library Manager:
Adafruit BMP5xx
Adafruit LSM6DS
Adafruit Unified Sensor
Adafruit BusIO
TinyGPSPlus
ArduinoJson
LoRa
```

---

## 🗂️ Estruturas de Dados
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

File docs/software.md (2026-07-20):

# Software Documentation - Onboard Computer

## Overview

The Flight Computer v2.0 firmware runs on an **ESP32-S3** (the v2.0 target
platform; the earlier ESP32-C3 SuperMini was used for the prototype/dev
firmware). It uses a FreeRTOS multi-task architecture, managing sensors,
communication and parachute control during flight.
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

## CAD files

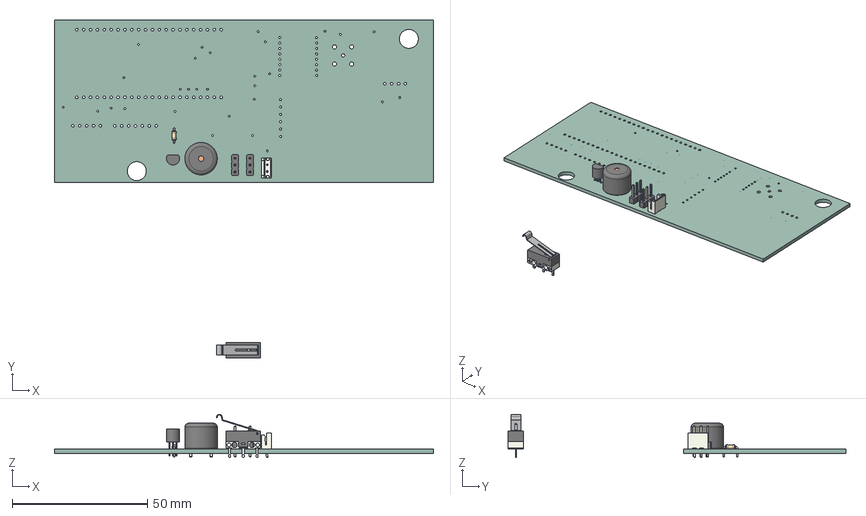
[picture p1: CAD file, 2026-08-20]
hardware/mechanical/electronics/electronics.step
140.0 x 124.7 x 16.0 mm
R_Axial_DIN0204_L36mm_D16mm_P508mm_Horizontal
PinHeader_1x03_P254mm_Vertical x 2
JST_B2B_EH_A
Bottom001
Top001
Plunger001
Lever_16U001
Pin_NO005
Pin_C005
Pin_NC005
Buzzer_12x95RM76
TO-92_Inline_Narrow
electronics-unsaved-export-J35aJb_PCB

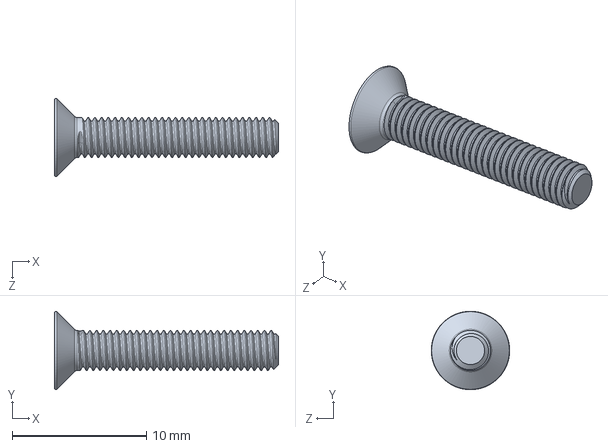
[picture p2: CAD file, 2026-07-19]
hardware/mechanical/standoff/m3_screw_15.SLDPRT
16.7 x 5.83 x 5.84 mm

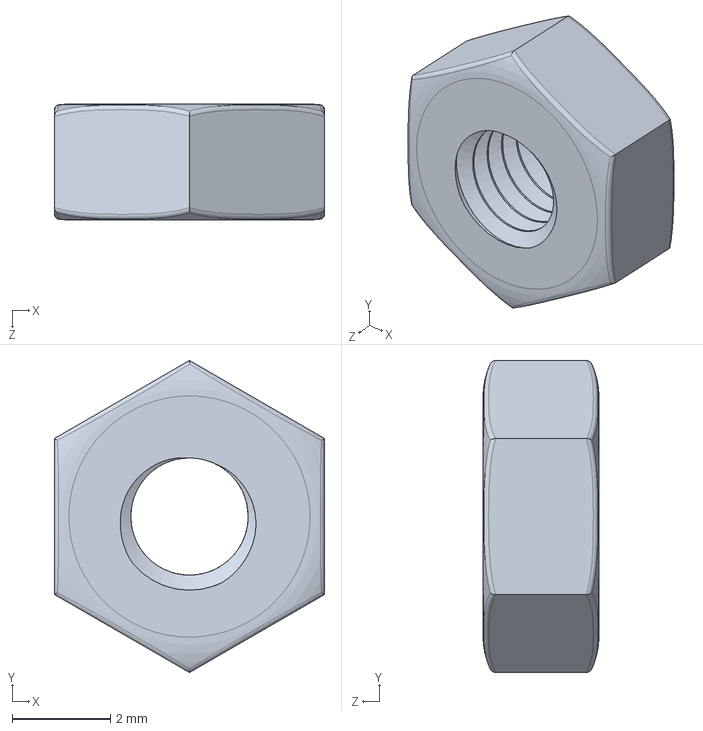
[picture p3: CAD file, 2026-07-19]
hardware/mechanical/standoff/m3_nut.SLDPRT
5.50 x 6.35 x 2.36 mm

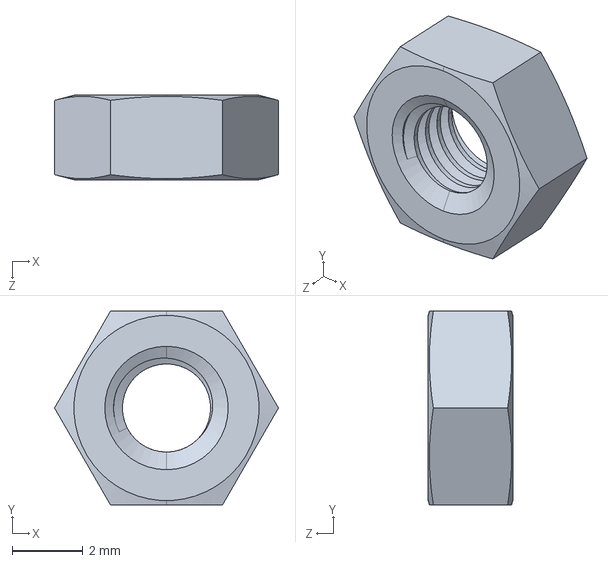
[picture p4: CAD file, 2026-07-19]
hardware/mechanical/standoff/m3_nut_2_4.SLDPRT
6.35 x 5.50 x 2.40 mm

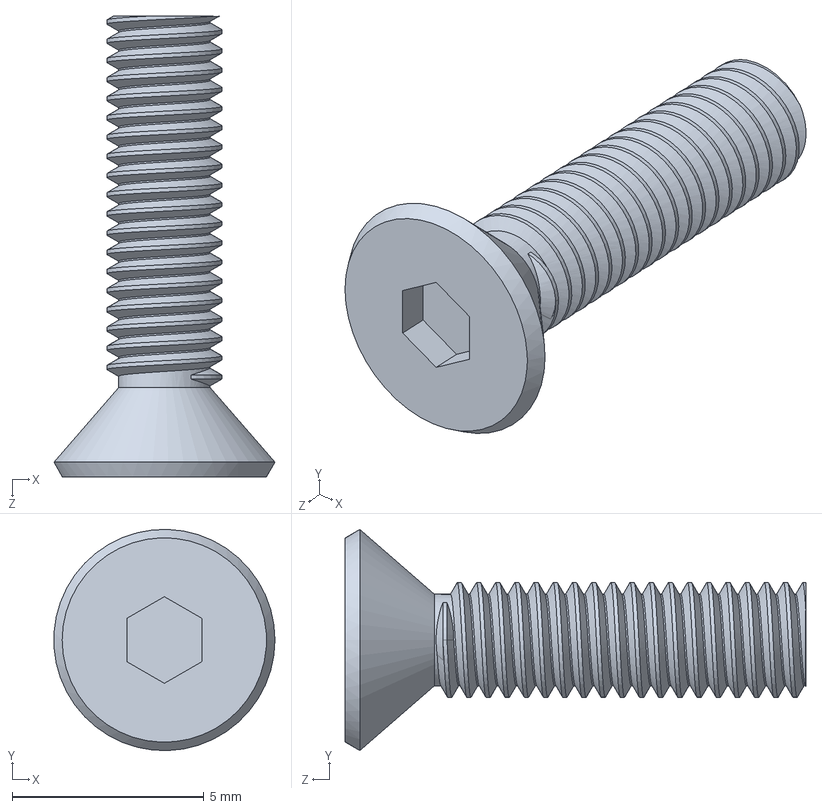
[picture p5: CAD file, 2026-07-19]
hardware/mechanical/standoff/m3_screw_12.SLDPRT
5.76 x 5.76 x 12.0 mm

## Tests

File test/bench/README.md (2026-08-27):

# Bench Self-Test (`test/bench/`)

Interactive self-test for every flight-computer sensor, module and actuator.
Run on the bench with the full stack wired as for flight.

## Flash & run

```bash
arduino-cli compile --fqbn esp32:esp32:esp32s3 test/bench
arduino-cli upload -p /dev/ttyACM0 --fqbn esp32:esp32:esp32s3 test/bench
# Serial monitor at 115200
```

## Commands

Send a single letter over Serial (115200):

| Cmd | Test |
|-----|---|
| `a` | **ALL** — runs every test sequentially, prints grand total |
| `b` | Barometer: BMP585 @0x7E primary, BMP280 @0x76/0x77 fallback; pressure/temp ranges + repeatability (sd < 0.5 hPa over 10 samples) |
| `i` | IMU: LSM6DS3 @0x6B; accel ~1g at rest, gyro < 0.35 rad/s at rest, temp, bus health (20 reads < 200 ms) |
| `g` | GPS: NEO-8M UART1 RX=17/TX=18 @9600; NMEA flow, checksum validity, fix |
| `l` | LoRa: RFM95W SPI 12/13/11 CS=10 RST=4 DIO0=5 @915 MHz; init, params, TX packet (endPacket==1), 3 s RX window |
| `f` | Filesystem: SD @CS=14 (type + write/read), falls back to LittleFS |
| `s` | Servo: 3x CLOSED->OPEN->CLOSED sweeps on GPIO7 (**actuator moves**) |
| `z` | Buzzer: 3 beeps on GPIO6 (audible verdict is manual) |
| `?` | List commands |

## Latest bench result (2026-08-27)

**18 PASS / 5 FAIL** — full log:

- BMP585 @0x7E: **FAIL (hardware absent)** — BMP280 fallback active, all checks
  PASS (920.47 hPa, 22.01 C, repeatability sd=0.0066 hPa).
- LSM6DS3: begin/accel/temp/bus PASS; gyro offset FAIL at rest
  (0.22/-0.88/-0.65 rad/s — re-test with board still; possible static bias).
- GPS: **FAIL was wiring** — GPS TX physically on GPIO17 (raw sniffer
  `test/gps_diag/` proved it). After the `config.h` swap (RX_GPS=17,
  TX_GPS=18): 4/4 PASS, 11 sats, 3D fix.
- LoRa: all PASS (TX endPacket==1; RX window empty without a second radio — normal).
- SD: all PASS (SDHC 7.7 GB, write/read round-trip).
- Servo: attach + 3 sweeps PASS (mechanical verdict manual).
- Buzzer: executed (audible verdict manual; user reports low volume —
  hardware review in progress: resistor/transistor drive, passive-vs-active type).

## Notes

- Pinout/constants in `bench.ino` are a **mirror of `firmware/config.h`** —
  keep in sync (this bit us once already: the GPS swap had to be applied in
  both places).
- The SD test writes/removes `/bench.txt`; LittleFS test writes `/bench.txt`.
- Servo test is the same actuator as the parachute door — keep fingers clear.

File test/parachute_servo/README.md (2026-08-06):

# Teste de Bancada — Servo do Paraquedas sob Carga Real (Risco nº 4)

**Local:** `test/parachute_servo/` · **Sketch:** `parachute_servo.ino` · **Analisador:** `extras/FSM_tester/analyze_servo_open_times.py`

## 1. Objetivo e contexto (por que este teste existe)

O firmware de voo (`firmware/parachute_module.cpp`, `firmware/config.h`) abre o
paraquedas com um único comando: `ParachuteServo.write(SERVO_OPEN)` (0°), partindo
de `SERVO_CLOSED` (90°), e depois apenas seta uma flag lógica
(`g_parachuteActuated`). **Não existe feedback**: não há fim de curso, nem medição
de corrente, nem confirmação de que a porta do compartimento realmente abriu.

Risco nº 4 do flight-computer: **se a porta travar, o velame empacotado exigir
mais torque do que o servo entrega, ou o elástico/mola empurrar o servo de volta
(back-drive), o servo trava (stall) sem o firmware perceber** — e o paraquedas
não abre no apogeu (regra inegociável: deploy no apogeu; `PARACHUTE_MIN_ALTITUDE`
= 50 m é só guarda de solo).

Este teste de bancada valida o conjunto **servo + mecanismo real** (porta + velame
empacotado + elástico/mola, se existir) medindo:

1. **Abertura completa** sob carga real (porta abre até o fim de curso).
2. **Tempo** comando → abertura total (com microswitch de bancada ou cronômetro).
3. **Repetibilidade** — 20 tentativas, estatística (média, desvio, pior caso).
4. **Falhas de movimento** — tempo acima do limite, porta que não segura aberta.
5. **Corrente de stall** — medida com multímetro em série (procedimento na seção 5).

> ⚠️ **Escopo:** teste de BANCADA. Não substitui o teste de integração em voo
> real, mas é o primeiro portão de aprovação do mecanismo de deploy. O microswitch
> é **fixture de bancada**, não é hardware de voo.

## 2. Materiais

| Item | Especificação |
|---|---|
| ESP32-S3 (mesma placa do voo) | Para reproduzir o mesmo PWM do firmware |
| Servo do paraquedas | O mesmo servo real do foguete (ver nota na seção 8) |
| Carga real | Porta do compartimento + velame empacotado + elástico/mola (mesma montagem do voo) |
| Microswitch de bancada (recomendado) | Fim de curso preso na estrutura: a porta o aciona ao abrir totalmente (liga FEEDBACK_PIN → GND) |
| Multímetro | Modo corrente (A), de preferência com **peak-hold**; ponteiras jacaré |
| Fonte / bateria 5 V | Mesma alimentação do voo (o BEC entrega 5 V / 3 A; ver seção 5) |
| Cabo USB + terminal serial | 115200 baud |
| Cronômetro (fallback) | Se não houver microswitch |

## 3. Montagem (rig de bancada)

1. **Prenda a porta com a carga real**: monte o compartimento exatamente como no
   voo — porta articulada no eixo, velame empacotado dentro, elástico/mola
   tensionado no estado fechado (se o mecanismo tiver). A carga **precisa ser a
   real**, senão o teste não mede o risco.
2. **Servo**: sinal (amarelo/laranja) → GPIO 10 (`SERVO_PIN`); vermelho → +5 V;
   marrom → GND.
3. **Microswitch (opcional, recomendado)**: fixe na estrutura do compartimento de
   forma que a porta, **totalmente aberta**, pressione o botão. Ligue
   `FEEDBACK_PIN` (GPIO 4, padrão do sketch) → microswitch → GND. O sketch usa
   `INPUT_PULLUP`; porta aberta = nível `LOW`. Se não usar microswitch, deixe
   `FEEDBACK_PIN = -1` no sketch (modo manual, seção 4.4).
4. **Multímetro em série** (para corrente): corte/estenda o fio vermelho do servo
   e ligue o multímetro em série entre a fonte 5 V e o servo. Configure o modo
   **A (corrente)**, porta 10 A se disponível, e ative **peak-hold** para capturar
   o pico.
5. **Compile e grave**:
   ```bash
   arduino-cli compile --fqbn esp32:esp32:esp32s3 test/parachute_servo
   arduino-cli upload -p /dev/ttyUSB0 --fqbn esp32:esp32:esp32s3 test/parachute_servo
   ```
   Abra o monitor serial a **115200 baud**.

> 🔒 **Atenção:** não altere nada em `hardware/electronics/**` — contém mudanças
> pré-existentes de outro trabalho. Este teste vive em `test/` e `extras/`.

## 4. Procedimento

### 4.1 Regras gerais

- **Fixe os critérios ANTES do teste** (seção 6). Não afrouxe critérios depois de
  ver os resultados — se falhar, corrija o mecanismo.
- Entre cada tentativa: **re-empacote o velame e feche a porta** (a carga precisa
  ser re-armada do zero, igual ao pré-voo).
- Registre o log serial completo (copie/cole no analisador, seção 7).

### 4.2 Sequência de teste (20 tentativas)

1. Power-on: o sketch arma o servo em `CLOSED` (90°) — porta fechada/travada.
2. Feche a porta manualmente e re-empacote o velame (estado de pré-voo).
3. Envie **`o`** no serial → o sketch varre o servo de `CLOSED` a `OPEN` (90° → 0°)
   e mede o tempo até o microswitch acusar abertura total (ou pede o tempo do
   cronômetro, no modo manual).
4. O sketch segura `OPEN` por `HOLD_MS` (2 s) verificando que a porta **continua
   aberta** (elástico/mola não pode empurrar o servo de volta).
5. Registra a linha CSV (`RUN,OPEN_MS,TRIPPED,OPEN_FAIL,HOLD_FAIL`), volta para
   `CLOSED` e imprime `PASS`/`FAIL`.
6. Repita os passos 2–5 até **20 tentativas** (`REPETITIONS`). Envie **`s`** para
   ver a estatística parcial/quando quiser.
7. Ao final, envie **`s`** e registre o resumo. **Passe o veredito** (seção 6).

### 4.3 Medição de corrente (stall)

- Com o multímetro em série + peak-hold, anote o **pico de corrente de abertura**
  em cada tentativa (ou ao menos nas 20).
- Para a **corrente de stall real (rotor travado)**: com o mecanismo DESARMADO
  (sem porta), envie **`b`** — o sketch dá 2 s de aviso, vai a `OPEN` e segura por
  `STALL_HOLD_MS` (2 s) enquanto você **segura o braço do servo com a mão**,
  impedindo o movimento. Leia o pico no multímetro. Solte ao terminar.
  > ⚠️ Faça o teste bloqueado **por último e brevemente**: rotor travado = corrente
  > máxima + aquecimento. Não repita várias vezes seguidas.

### 4.4 Modo manual (sem microswitch)

Com `FEEDBACK_PIN = -1`, o sketch não detecta abertura: ele varre, imprime o
número da tentativa e pede `Enter measured open time (ms):`. Use um cronômetro
(ou vídeo em câmera lenta) do momento do comando até a porta abrir totalmente e
digite o valor. A verificação de *hold* fica desabilitada nesse modo — a porta
deve ser observada manualmente durante os 2 s seguintes.

## 5. Medição de corrente — como e por quê

O ESP32 não mede corrente (não há sensor no hardware). O procedimento é:

- Multímetro em série no fio **vermelho** (5 V) do servo, modo corrente, porta
  alta (10 A) ou peak-hold.
- Medir: (a) pico de corrente durante a abertura sob carga (cada tentativa) e
  (b) stall de rotor travado (comando `b`).
- **Por que importa:** a fonte de voo é um BEC 5 V / 3 A compartilhado com buzzer
  (~30 mA) e LoRa (~120 mA). Se a corrente de stall exceder a folga do rail, a
  tensão 5 V cai, o torque cai ainda mais e o ESP32 pode resetar — um falha dupla.
- **Corrente esperada:** para servo padrão 5 V com engrenagem metálica na faixa
  de ~4,8 kg·cm, o stall fica tipicamente entre **1,0 e 2,0 A**. Confirme contra
  o datasheet do servo real (ver seção 8).

## 6. Critérios de aprovação

Fixe antes de começar. Padrões sugeridos (ajuste às medidas do servo real **antes**
do primeiro run — nunca depois):

| # | Critério | Limite | Verificação |
|---|---|---|---|
| A | Abertura completa (porta no fim de curso) | **20/20 tentativas** | microswitch tripado (ou cronômetro, modo manual) |
| B | Tempo comando → abertura total | **< 1000 ms** em cada tentativa | `OPEN_MS` do log (servo especifica ~0,23 s/60° → ~345 ms sem carga; limite com folga para carga) |
| C | Porta permanece aberta (sem back-drive) | **20/20 tentativas** por ≥ 2000 ms | hold check do sketch |
| D | Corrente de pico de abertura | **≤ 1500 mA** (típico) | multímetro peak-hold |
| E | Corrente de stall (rotor travado) | **≤ 2500 mA** (teto do BEC: 3 A − buzzer − LoRa ≈ 2,7 A, com margem) | comando `b` + multímetro |

**Resultado final:** PASS se A–E passarem. Qualquer falha = FAIL do mecanismo
(só o servo em si não é aprovado).

## 7. Análise dos tempos

Copie o log serial (linhas `RUN,OPEN_MS,...`) para um arquivo e rode:

```bash
python3 extras/FSM_tester/analyze_servo_open_times.py log_servo.csv
# ou cole via stdin:
python3 extras/FSM_tester/analyze_servo_open_times.py < log_servo.csv
```

O script calcula média, desvio, pior caso e o veredito contra os critérios B/C
(exit code 0 = PASS, 1 = FAIL).

## 8. O que fazer se falhar

| Sintoma | Provável causa | Ação |
|---|---|---|
| Abertura lenta (> 1000 ms) ou não abre | Torque insuficiente | Servo maior/mais torque; alimentar o servo com 6 V direto (se o BEC permitir); verificar sag de tensão no 5 V durante o stall (fonte fraca derruba o torque) |
| Trava em posição intermediária | Atrito / interferência da porta | Lubrificar dobradiça/trilho; verificar se o velame empacotado prende na borda; aliviar pontos de contato |
| Porta não segura aberta (back-drive) | Elástico/mola forte demais para o servo em `OPEN` | Reduzir pré-carga da mola; mudar ponto de fixação do braço (mais alavanca); ou servo com maior torque de holding |
| Corrente de stall acima do teto | Servo subdimensionado / BEC marginal | Servo com menor corrente de stall; fonte dedicada para o servo; revisar o rail 5 V |
| Pico de corrente na abertura > 1,5 A | Mecanismo com muita resistência | Reduzir atrito antes de trocar o servo (item 2 acima) |

Regra geral: **primeiro reduza atrito/pré-carga, depois aumente torque** — a
margem de torque medida na bancada é a margem que existe em voo.

## 9. Registro de resultados (preencher na execução)

| Data | Operador | Servo (modelo) | Trials | Aberturas OK | Tempo médio (ms) | Pior caso (ms) | I pico abertura (mA) | I stall (mA) | Veredito |
|---|---|---|---|---|---|---|---|---|---|
| | | | 20 | | | | | | |

## 10. Notas técnicas

- **Servo real a confirmar:** `docs/hardware.md` especifica "metal gears, ~4,8
  kg·cm, ~9 g" — 9 g é faixa de micro servo (~1,8 kg·cm, ~0,7 A de stall), 4,8
  kg·cm é faixa de servo de ~55 g (~2 A de stall). **Identifique o modelo real e
  ajuste os critérios D/E ao datasheet** antes do primeiro run.
- **Constantes espelhadas:** `SERVO_PIN`, `SERVO_OPEN`, `SERVO_CLOSED` duplicam
  `firmware/config.h` de propósito (o sketch é standalone). Se mudar no firmware,
  mude aqui também.
- **Critério B × firmware:** o firmware manda `write(SERVO_OPEN)` uma única vez e
  segue a vida (não re-escrita periódica). O hold check mede se o servo segura a
  posição sozinho sem refresh — se falhar, o firmware pode precisar re-escrever a
  posição periodicamente após o deploy (discutir com o time de firmware).

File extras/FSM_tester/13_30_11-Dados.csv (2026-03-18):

millis | lat | lon | sat | alt | data | hora | altp | p | ax | ay | az | gx | gy | gz | pqd
7060 | -22.590936 | -42.764552 | 10 | 11.70 | N/A | 13:30:11 | -0.10 | 1026.58 | 1.99 | 9.19 | 0.83 | -0.08 | 0.01 | 0.00 | 0
7260 | -22.590936 | -42.764552 | 10 | 11.70 | N/A | 13:30:11 | 0.03 | 1026.57 | 1.91 | 9.36 | 0.71 | -0.06 | 0.02 | 0.03 | 0
7460 | -22.590936 | -42.764552 | 10 | 11.70 | N/A | 13:30:11 | -0.11 | 1026.59 | 1.99 | 9.40 | 0.89 | -0.08 | 0.06 | 0.02 | 0
7660 | -22.590936 | -42.764552 | 10 | 11.70 | N/A | 13:30:11 | -0.11 | 1026.59 | 1.79 | 9.26 | 0.91 | -0.09 | 0.03 | 0.02 | 0
7911 | -22.590937 | -42.764552 | 10 | 11.70 | 2025/6/2 | 13:30:13 | -0.30 | 1026.61 | 1.94 | 9.57 | 1.23 | -0.12 | 0.03 | 0.07 | 0
8137 | -22.590937 | -42.764552 | 10 | 11.80 | 2025/6/2 | 13:30:13 | -0.20 | 1026.60 | 1.87 | 9.23 | 1.58 | 0.04 | 0.09 | 0.09 | 0
8363 | -22.590937 | -42.764552 | 10 | 11.80 | 2025/6/2 | 13:30:13 | -0.16 | 1026.59 | 1.18 | 9.27 | -0.17 | 0.33 | 0.46 | 0.14 | 0
8594 | -22.590937 | -42.764552 | 10 | 11.80 | 2025/6/2 | 13:30:13 | -0.04 | 1026.58 | 1.55 | 9.39 | -0.59 | 0.22 | -0.14 | -0.01 | 0
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

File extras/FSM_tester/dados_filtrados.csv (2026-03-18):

millis | lat | lon | sat | alt | data | hora | altp | p | ax | ay | az | gx | gy | gz | pqd
0.0 | -22.590942 | -42.764539 | 12 | 12.5 | 2025/6/2 | 13:37:46 | 2.36 | 1026.28 | -1.09 | 19.61 | 2.81 | 0.23 | -1.27 | -0.32 | 0
0.241 | -22.59094 | -42.764538 | 12 | 17.7 | 2025/6/2 | 13:37:47 | 8.23 | 1025.57 | 2.18 | 19.61 | 2.99 | 0.87 | 2.32 | -0.37 | 0
0.497 | -22.59094 | -42.764538 | 12 | 17.7 | 2025/6/2 | 13:37:47 | 16.98 | 1024.51 | -5.26 | 19.61 | 1.46 | -1.08 | 1.9 | -0.07 | 0
0.746 | -22.59094 | -42.764538 | 12 | 17.7 | 2025/6/2 | 13:37:47 | 24.59 | 1023.58 | -4.7 | 19.61 | 7.66 | 0.35 | 2.75 | 0.54 | 0
0.997 | -22.59094 | -42.764538 | 12 | 17.7 | 2025/6/2 | 13:37:47 | 40.35 | 1021.67 | 6.75 | 19.61 | 8.54 | -0.02 | 0.5 | 0.35 | 0
1.285 | -22.59094 | -42.764538 | 12 | 17.7 | 2025/6/2 | 13:37:47 | 63.9 | 1018.82 | 1.89 | 9.88 | -1.78 | 0.23 | -0.37 | 0.23 | 0
1.52 | -22.590869 | -42.764568 | 12 | 16.5 | 2025/6/2 | 13:37:48 | 78.05 | 1017.11 | -0.34 | -0.87 | -1.61 | 0.06 | -0.9 | 0.09 | 0
1.758 | -22.590869 | -42.764568 | 12 | 16.5 | 2025/6/2 | 13:37:48 | 95.84 | 1014.96 | 0.51 | -5.23 | -0.64 | -0.05 | -0.99 | 0.07 | 0
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

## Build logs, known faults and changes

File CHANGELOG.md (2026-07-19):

# Changelog

All notable changes to this project will be documented in this file.

The format is based on [Keep a Changelog](https://keepachangelog.com/en/1.0.0/),
and this project adheres to [Semantic Versioning](https://semver.org/).

## [Unreleased]

### Fixed

- **Buffer overflow fix in GPSModule** (`GPSModule.cpp:59,66`):
  - Replaced `sprintf()` with `snprintf()` in `getTimeString()` and `getDateString()`
  - Eliminates risk of buffer overflow with malformed GPS data

- **Sensor fallback on corrupted readings** (`BMP585Sensor.cpp`):
  - Added NaN and range validation (`-500` to `50000` m) on altitude reads
  - Invalid readings silently discarded — last known good values preserved
  - Prevents NaN propagation to FSM from transient sensor glitches

### Changed

- **Private member naming aligned with v2.0 convention** (`BMP585Sensor`, `LSM6DS3Sensor`):
  - All private members renamed from `snake_case` to `_camelCase` per AGENTS.md
  - Affects `_basePressure`, `_altitude`, `_prevAltitude`, `_accelX`, `_totalAccel`, etc.
  - `smoothFilter()` changed to `static` (no instance state dependency)

### Documentation

- Fixed critical pin table mismatch in `docs/hardware.md` (was showing C3 pins, now matches S3 config.h)
- Rewrote `docs/flowchart.md` from v1.0 to v2.0 (FreeRTOS tasks + 4-state FSM)
- Rewrote `CONTRIBUTING.md` for v2.0 (S3 target, OOP, FreeRTOS patterns)
- Updated `AGENTS.md` — v2.0 status "in planning" → "implemented", 868E6 → 915E6
- Updated `REFACTORING_PLAN.md` — all 10 phases marked complete
- Cleaned up dead v1.0 constants from `config.h` (`INTERVAL`, `ALTITUDE_THRESHOLD`, `VELOCITY_THRESHOLD`, `ALTITUDE_DROP_THRESHOLD`)

---

## [2.0.0] - 2026-07-19

### Added

- **Phase 1-2: Project structure and base interfaces**
  - `firmware/sensors/ISensor.h` — Abstract interface for all sensors (BMP585, LSM6DS3, GPS)
  - `firmware/flight/SensorData.h` — Shared data structures (SensorData, LogMessage)
  - Sensor abstraction layer enabling polymorphic sensor implementations
  - FreeRTOS-compatible data structures for inter-task communication via queues
  - Complete Doxygen documentation for all interfaces

- **Phase 3: BMP585Sensor class**
  - Barometric altitude, pressure, temperature reading
  - Vertical velocity (Vz) via numerical differentiation, clipped to ±200 m/s
  - NaN/Inf and range validation with fallback to last known good value
  - IIR low-pass filter (alpha=0.2) for accelerometer data

- **Phase 4: LSM6DS3Sensor class**
  - 6-axis accelerometer + gyroscope with safety validations
  - NaN/Inf rejection and range checking (±200 m/s² accel, ±2000 °/s gyro)
  - Vector accessors via pointer parameters (`getAcceleration`, `getGyroscope`)

- **Phase 5: GPSModule class**
  - Non-blocking NMEA parsing via TinyGPS++ at 5Hz
  - HardwareSerial dependency injection for testability
  - GPS time used for CSV file naming (NOFIX fallback)

- **Phase 6: 4-state Flight State Machine**
  - IDLE → ASCENT → DESCENT → LANDED with sub-event flags (liftoff, burnout, apogee, freefall, parachute)
  - Thresholds validated against real flight data (1,873 points from `13_30_11-Dados.csv`)
  - IIR filter with seed on first reading (avoids transient)
  - Parachute deploy with multi-cycle confirmation (3 cycles of stable negative Vz)
  - Ground guard (50m) preventing deployment near terrain

- **Phase 7: FreeRTOS multi-task architecture**
  - **FlightControlTask** (Core 1, Priority 20, 50Hz): sensor reads + FSM + parachute + watchdog
  - **TelemetryTask** (Core 0, Priority 5, 5Hz): GPS + queue drain + LoRa + file logging
  - **LoggerTask** (Core 0, Priority 1): async log queue with level filtering
  - Queue-based inter-task communication (no shared variables)
  - ESP32 TWDT armed inside the running task (not in init)
  - Performance metrics (cycle count, overruns, queue drops, exec time)

- **Phase 8: firmware.ino integration**
  - `setup()` delegates to `initFlightControlTask()` / `initTelemetryTask()` / `initLoggerTask()`
  - Safe-hold on critical failure (infinite loop + buzzer) — no `ESP.restart()`
  - `loop()` blocks on `vTaskDelay(portMAX_DELAY)`; all work in FreeRTOS tasks

- **Phase 9: Module adaptation**
  - `parachute_module` — Servo actuator (one-shot, idempotent deploy)
  - `lora_module` — RFM95W at 915 MHz, SF7, BW125k, CR4/5, CRC enabled
  - `filesystem_module` — SD card primary + LittleFS fallback, transparent dispatch
  - `buzzer_module` — Status tones (init success/failure)

- **Phase 10: Telemetry format (22 fields)**
  - CSV format aligned with `recovery-webui` receiver: `TEAM_ID,millis,count,altp,temp,umi,p,gx,gy,gz,ax,ay,az,vz,maxAltitude,state,alt,lat,lon,sat,parachute,rssi`
  - Single `snprintf` call (no heap fragmentation)
  - GPS enrichment in TelemetryTask (not FlightControlTask)

### Changed

- Migrated from v1.0 procedural architecture to v2.0 Object-Oriented design
- Restructured firmware directory: `sensors/`, `flight/`, `modules/`
- **FSM simplified to 4 main states** with internal event flags (was 7-state model)
- Replaced BMP280 with BMP585 (I2C, improved accuracy)
- Replaced MPU6050 with LSM6DS3 (6-axis, better range)
- Replaced NEO-6M GPS with NEO-8M (multi-constellation)
- Removed WiFi AP + Web server (v1.0 feature, not needed in v2.0)
- Updated `docs/software.md` with new module structure and component mapping
- Pin table in `docs/hardware.md` updated for ESP32-S3 pinout
- `docs/flowchart.md` rewritten for FreeRTOS + 4-state FSM
- `CONTRIBUTING.md` rewritten for v2.0 workflows

### Fixed

- **Critical Safety Initializations** (commit 4b0c239):
  - All SensorData struct fields now have safe default values
  - LogMessage buffer initialized with zero-terminator
  - Prevents undefined behavior from uninitialized variables
  - Ensures parachute_deployed flag cannot be random on startup
  - Protects against NaN propagation in FSM transitions

### Documentation Added

- `docs/adr/002-sensor-abstraction.md` — Architectural Decision Record for ISensor interface

---

## [1.0.0] - 2026-01-27

### Added

- Initial project structure
- Base firmware for ESP32-C3 Super Mini
- Altitude monitoring system (MPU6050 sensor)
- GPS integration
- LoRa communication with operational base
- Telemetry storage in LittleFS
- Web interface for data access
- Component unit tests
- Software and hardware documentation

### Release Notes

- First functional version of the onboard computer
- Parachute deployment system still under testing
- Sensor calibration required before flight

---

## Versioning Guide

### MAJOR (X.0.0)

- Incompatible changes to firmware API or data structure

### MINOR (0.X.0)

- New features backward compatible with previous version
- Functionality improvements

### PATCH (0.0.X)

- Bug fixes
- Performance optimizations
- Documentation updates

## How to Report Changes

When making commits or pull requests, use the following categories:

- `feat:` for new features
- `fix:` for bug fixes
- `docs:` for documentation
- `test:` for tests
- `refactor:` for code refactoring
- `perf:` for performance improvements
- `chore:` for maintenance tasks

Example: `feat: add temperature sensor`

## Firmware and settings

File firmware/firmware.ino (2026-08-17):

/**
 * @file firmware.ino
 * @brief Main firmware entry point for #11 Flight Computer (Avionics System)
 * 
 * This is the main program file for a rocket flight computer that handles
 * sensor data collection, parachute deployment, telemetry transmission, and
 * data storage. The system uses a modular architecture with separate header files
 * for each subsystem.
 * 
 * System capabilities:
 * - Altitude and atmospheric pressure monitoring (BMP585)
 * - Inertial measurement unit for orientation (LSM6DS3)
 * - GPS position and time tracking
 * - Long-range telemetry via LoRa radio
 * - Autonomous parachute deployment based on flight profile (apogee, Option A)
 * - Data logging to onboard flash storage (LittleFS)
 * - Audio feedback via buzzer for system status
 * 
 * Flight phases:
 * 1. Initialization: System startup and sensor calibration
 * 2. Pre-launch: Monitoring and data collection on ground
 * 3. Ascent: High-frequency data logging during powered flight
 * 4. Apogee detection: Tracking maximum altitude
 * 5. Descent: Parachute deployment at apogee and controlled landing
 * 6. Recovery: Post-flight data access via storage retrieval
 * 
 * @note All configuration parameters are in config.h
 * @note FlightControlTask runs at 50Hz (FLIGHT_CONTROL_PERIOD_MS);
 *       TelemetryTask and LoggerTask run at 5Hz.
 * 
 * @author Serra Rocketry
 * @date 2026
 */

//==============================================================================
// LIBRARY INCLUDES
//==============================================================================

#include <Wire.h>    // I2C communication for BMP585 and LSM6DS3
#include <SPI.h>     // SPI communication for LoRa module

//==============================================================================
// MODULE INCLUDES
//==============================================================================

#include "config.h"             // Global configuration and constants

#include "sensors/BMP585Sensor.h"
#include "sensors/LSM6DS3Sensor.h"
#include "sensors/GPSModule.h"
#include "flight/FlightStateMachine.h"
#include "flight/FlightControlTask.h"
#include "flight/TelemetryTask.h"
#include "flight/LoggerTask.h"


#include "modules/buzzer_module.h"
#include "modules/filesystem_module.h"
#include "modules/lora_module.h"
#include "modules/parachute_module.h"

//==============================================================================
// SETUP - ONE-TIME INITIALIZATION
//==============================================================================

/**
 * @brief Initialize all system components and prepare for flight
 * 
 * This function runs once at power-on and delegates subsystem startup to the
 * task init functions (each owns its objects, queues and watchdog):
 *  - initFlightControlTask(): BMP585 + LSM6DS3 + FSM + sensorDataQueue + servo
 *  - initTelemetryTask(): GPS + telemetry queue consumer + LoRa/file fan-out
 *  - initLoggerTask(): logQueue + Serial/file logger
 * 
 * On any critical init failure the system restarts (ESP.restart).
 * 
 * @note Serial monitor must be set to 115200 baud
 * @note The watchdog (TWDT) is armed inside taskFlightControl once it is
 *       actually running, not here, to avoid a dangling armed watchdog.
 *
 * On any critical init failure the system prints the error, flushes Serial,
 * and enters an infinite loop with the buzzer blinking — it does NOT call
 * ESP.restart() to avoid losing state in flight.
 * 
 * @see setup() is called automatically once by Arduino framework
 */
void setup() {
  Serial.begin(115200);
  Wire.begin(I2C_SDA, I2C_SCL);
  pinMode(BUZZER_PIN, OUTPUT);

  // Configure the SPI bus up front (LoRa pins SCK=12/MISO=13/MOSI=11, CS=10).
  // initTelemetryTask() calls setupStorage() (SD.begin) BEFORE setupLoRa(),
  // and SD.begin uses the global SPI object — without this early SPI.begin(),
  // the SD card is probed on the ESP32-S3 default SPI pins and always falls
  // back to LittleFS. setupLoRa() re-issues SPI.begin() with the same pins
  // (idempotent).
  SPI.begin(LORA_SCK, LORA_MISO, LORA_MOSI, SS_LORA);

  bool initOk = true;
  String initFail = "";

  if (!initFlightControlTask()) {
    initFail = "FATAL: FlightControl init failed (sensors/servo?)";
    initOk = false;
  } else if (!initTelemetryTask()) {
    initFail = "FATAL: Telemetry init failed (LoRa/FS/GPS?)";
    initOk = false;
  } else if (!initLoggerTask()) {
    initFail = "FATAL: Logger init failed";
    initOk = false;
  }

  if (!initOk) {
    // Safe-hold: do NOT reboot in a loop (would lose state in flight and
    // hides the error). Print clearly, flush, and blink the buzzer as alarm.
    Serial.println(initFail);
    Serial.flush();
    Serial.println("Halting — check wiring/sensors. Buzzer alarm active.");
    Serial.flush();
    for (;;) {
      digitalWrite(BUZZER_PIN, (millis() / 500) % 2);
      delay(500);
    }
  }
}

void loop() {
  vTaskDelay(portMAX_DELAY);

}

//==============================================================================
// MAIN LOOP - CONTINUOUS OPERATION
//==============================================================================

/**
 * @brief Main flight computer control loop
 * 
 * Intentionally empty: all real-time work happens in the FreeRTOS tasks
 * created by the init functions (FlightControl @50Hz, Telemetry @5Hz,
 * Logger @5Hz). The loop blocks forever on portMAX_DELAY so the Arduino
 * framework's loop() does not spin.
 * 
 * Parachute deployment (safety-critical) is decided by FlightStateMachine
 * on apogee detection (Option A) and actuated by taskFlightControl — not
 * here.
 */

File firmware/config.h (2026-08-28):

/**
 * @file config.h
 * @brief Global configuration file for the avionics system
 * 
 * This file contains all pin definitions, constants, and parameters
 * used throughout the system. Centralizing configurations here makes
 * maintenance and parameter modifications easier.
 * 
 * @author #11
 * @date 2026
 */

#ifndef CONFIG_H
#define CONFIG_H

#include <Arduino.h>

//==============================================================================
// LORA COMMUNICATION CONFIGURATION
//==============================================================================

/**
 * LoRa module operating frequency in Hz
 * 915 MHz is the ISM frequency for Brazil/Americas (matches receiver-lora).
 * (868 MHz is Europe — do not use here.)
 */
#define LORA_FREQ 915E6

/**
 * SPI bus pins shared between LoRa (RFM95W) and SD card.
 * Wired on the ESP32-S3-DEVKITC-1-N8R8 schematic (2026-08):
 *   SCK  = GPIO12, MISO = GPIO13, MOSI = GPIO11, CS_LORA = GPIO10
 * @note The LoRa 0.8.0 library uses the global SPI object. We remap the SPI
 *       bus to these pins via SPI.begin(SCK, MISO, MOSI, SS) in setupLoRa()
 *       (same approach as the receiver-lora firmware, which compiles/runs
 *       clean). Only CS/RST/DIO0 are passed to LoRa.setPins().
 */
#define LORA_SCK  12
#define LORA_MISO 13
#define LORA_MOSI 11
#define SS_LORA 10

/**
 * Reset pin for LoRa module (RFM95W).
 * Schematic: GPIO4 on ESP32-S3-DEVKITC-1-N8R8.
 */
#define RST_LORA 4

/**
 * DIO0 pin of LoRa module (IRQ / interrupt).
 * Schematic: GPIO5 on ESP32-S3-DEVKITC-1-N8R8.
 */
#define DIO0_LORA 5

/**
 * Synchronization word for LoRa communication
 * Ensures only devices with the same word communicate
 * Change this value to create isolated LoRa networks
 */
#define SYNC_WORD 0xF3

// Spreading factor / bandwidth / coding rate / TX power.
// Explicitly matched to the receiver (recovery-webui/components/receiver-lora)
// so the link connects. These are also the LoRa.h defaults, but we set them
// explicitly to avoid relying on library defaults.
#define LORA_SF       7      // Spreading Factor 7–12
#define LORA_BW       125E3  // Bandwidth Hz
#define LORA_CR       5      // Coding Rate (4/5)
#define LORA_TX_POWER 17     // dBm

//==============================================================================
// PIN DEFINITIONS - SD CARD (SPI, shares bus with LoRa)
//==============================================================================

/**
 * Chip Select pin for SD card module.
 * Shares the SPI bus with LoRa (SCK=12, MISO=13, MOSI=11, CS_LORA=10).
 * Schematic: GPIO14 on ESP32-S3-DEVKITC-1-N8R8.
 * @note If SD fails, data is saved to LittleFS (internal flash) automatically.
 */
#define SD_CS_PIN 14

/**
 * Flush file buffer every N samples when using SD card
 * Balances data safety vs. write endurance.
 */
static constexpr uint8_t FLUSH_EVERY_N = 10;

//==============================================================================
// PIN DEFINITIONS - ACTUATORS
//==============================================================================

/**
 * Digital pin connected to parachute servo motor.
 * Uses PWM to control servo position.
 * Schematic: GPIO7 on ESP32-S3-DEVKITC-1-N8R8.
 * @note Two servo footprints (M1, M2) on the schematic share this same PWM
 *       signal — confirm with the assembler whether the build uses one or both.
 */
#define SERVO_PIN 7

/**
 * Digital pin connected to piezoelectric buzzer.
 * Emits sound signals for status indication.
 * Schematic: GPIO6 on ESP32-S3-DEVKITC-1-N8R8.
 * @note Avoid GPIO0 (boot strap).
 */
#define BUZZER_PIN 6

/**
 * Tone frequency for the passive piezo buzzer (Hz).
 * @note Bench resonance sweep (test/bench `z`, 2026-08-27): loudest point
 *       of the 2.0-4.0 kHz scan. The piezo is PASSIVE — drive with tone()/
 *       LEDC square wave; digitalWrite DC produces no sound.
 */
#define BUZZER_TONE_HZ 2700

//==============================================================================
// PIN DEFINITIONS - I2C (SENSORS: BMP585 barometer, LSM6DS3 IMU)
//==============================================================================

/**
 * I2C data pin (SDA) for the sensor bus.
 * @note ESP32-S3 Arduino core default is SDA=8 / SCL=9. The BMP585 and
 *       LSM6DS3 drivers call begin_I2C() with no pins, so they use this
 *       default. Wire.begin() below also uses these. Keep the schematic
 *       wired to 8/9 (or change both here and the calls).
 */
#define I2C_SDA 8

/**
 * I2C clock pin (SCL) for the sensor bus.
 */
#define I2C_SCL 9

/**
 * I2C 7-bit address of the LSM6DS3 IMU.
 * Bench-measured via brute-force I2C scan (2026-08-27): responds at 0x6B
 * (the LSM6DS3 alternates 0x6A/0x6B depending on the SDO/SA0 strap).
 */
#define I2C_ADDR_LSM6DS3 0x6B

/**
 * I2C 7-bit address of the BMP585 barometer.
 * Bench-measured via brute-force I2C scan (2026-08-27): responds at 0x7E
 * (non-default; the BMP58x factory default is 0x76/0x77 selected by CSB).
 */
#define I2C_ADDR_BMP585 0x7E
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

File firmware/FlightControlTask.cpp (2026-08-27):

/**
 * @file FlightControlTask.cpp
 * @brief Implementation of the 50Hz flight control task
 *
 * @see FlightControlTask.h for API and configuration documentation
 * @see firmware/REFACTORING_PLAN.md - Fase 7
 */

#include "flight/FlightControlTask.h"

#include <esp_task_wdt.h>
#include <esp_timer.h>
#include <ESP32Servo.h>
#include <string.h>

#include "config.h"
#include "sensors/BMP585Sensor.h"
#include "sensors/LSM6DS3Sensor.h"
#include "modules/parachute_module.h"
#include "flight/FlightStateMachine.h"
#include "flight/LoggerTask.h"

TaskHandle_t  g_flightControlTaskHandle = nullptr;
QueueHandle_t sensorDataQueue           = nullptr;

namespace {

BMP585Sensor*       g_baro = nullptr;
LSM6DS3Sensor*       g_imu = nullptr;
FlightStateMachine*  g_fsm = nullptr;

bool  g_parachuteActuated = false;

// ── Free-fall backstop state (FSM-independent safety net) ───────────────────
// Own IIR-filtered acceleration so the detector never depends on the FSM
// internals: even if the state machine is stuck (e.g. restored to ASCENT
static uint16_t g_ffSustainedCycles = 0;
static bool     g_ffFilterSeeded    = false;
static float    g_ffFiltAx = 0.0f, g_ffFiltAy = 0.0f, g_ffFiltAz = 0.0f;

// ── Barometer-staleness contingency state ───────────────────────────────────
// Own IIR filter + liftoff latch: completely independent of FSM and backstop
// state. Covers the common-mode failure where the barometer freezes mid-flight
// (frozen last-good values are plausible, never NaN) — without it, neither the
// FSM nor the free-fall backstop would deploy.
static bool     g_baroStaleFilterSeeded = false;
static float    g_bsFiltAx = 0.0f, g_bsFiltAy = 0.0f, g_bsFiltAz = 0.0f;
static bool     g_bsLiftoffLatched = false;
static uint16_t g_bsSustainedCycles = 0;

// ── Pad arming state (risk #2) ──────────────────────────────────────────────
static char     armBuffer[16] = {0};
static int      armBufferLen  = 0;

/**
 * @brief FSM-independent free-fall detector (safety backstop)
 *
 * Fires once when total acceleration (IIR-filtered, alpha=0.2) stays below
 * FREEFALL_BACKSTOP_ACC_THRESHOLD for FREEFALL_BACKSTOP_CYCLES consecutive
 * cycles while the rocket is descending faster than FREEFALL_BACKSTOP_VZ and
 * still above FREEFALL_BACKSTOP_MIN_HEIGHT. Returns true exactly once, then
 * stays latched until the next reset() (via g_ffSustainedCycles saturation).
 *
 * Covers the failure mode the NVS persistence cannot: FSM alive but stuck in
 * the wrong state (IDLE after a reboot with no valid snapshot, or ASCENT
 * while actually falling) — the chute still opens at apogee.
 *
 * @note Validated offline: extras/FSM_tester/validate_freefall_backstop.py
 *       (never fires before apogee, fires 1-3s after the FSM deploy, never
 *       on pad vibration).
 * @return true when the backstop has just fired (deploy now)
 */
bool checkFreefallBackstop() {
  // Latch: once fired, keep returning true until a reboot/reset.
  if (g_ffSustainedCycles > FREEFALL_BACKSTOP_CYCLES) {
    return true;
  }

  float ax, ay, az;
  g_imu->getAcceleration(&ax, &ay, &az);

  if (!std::isfinite(ax) || !std::isfinite(ay) || !std::isfinite(az)) {
    return false;
  }

  // IIR low-pass, same alpha as the FSM (seed on first reading).
  if (!g_ffFilterSeeded) {
    g_ffFiltAx = ax;
    g_ffFiltAy = ay;
    g_ffFiltAz = az;
    g_ffFilterSeeded = true;
  } else {
    g_ffFiltAx += FILTER_ALPHA * (ax - g_ffFiltAx);
    g_ffFiltAy += FILTER_ALPHA * (ay - g_ffFiltAy);
    g_ffFiltAz += FILTER_ALPHA * (az - g_ffFiltAz);
  }

  const float acc = sqrtf(g_ffFiltAx * g_ffFiltAx +
                          g_ffFiltAy * g_ffFiltAy +
                          g_ffFiltAz * g_ffFiltAz);
  if (!std::isfinite(acc)) {
    return false;
  }

  const float height = g_baro->getAltitude();
  const float vz     = g_baro->getVerticalVelocity();

  const bool freefalling = (acc < FREEFALL_BACKSTOP_ACC_THRESHOLD &&
                            vz  < FREEFALL_BACKSTOP_VZ &&
                            height > FREEFALL_BACKSTOP_MIN_HEIGHT);
  if (freefalling) {
    g_ffSustainedCycles++;
    if (g_ffSustainedCycles == FREEFALL_BACKSTOP_CYCLES) {
      Serial.printf("[FlightControl] BACKSTOP: free-fall acc=%.2f vz=%.2f h=%.1f\n",
                    acc, vz, height);
      return true;
    }
  } else {
    g_ffSustainedCycles = 0;
  }
  return false;
}

/**
 * @brief Barometer-staleness contingency (IMU-only, FSM-independent)
 *
 * Fires when the barometer has been frozen for BARO_STALE_AGE_MS while the
 * rocket is in a sustained IMU-only free fall. The flight must have actually
 * started (accel > LIFTOFF_ACCEL_THRESHOLD seen at least once since boot —
 * never opens on the pad) and the last-good maxAltitude must be above the
 * ground guard (replaces the height check while the barometer is dead).
 *
 * @return true once armed and a BARO_STALE_SUSTAIN_CYCLES window of
 *         near-zero-g is confirmed; latches until reboot (one-shot via
 *         g_parachuteActuated in the caller)
 */
bool checkBaroStaleContingency() {
  if (g_bsSustainedCycles > BARO_STALE_SUSTAIN_CYCLES) {
    return true;  // already fired, latched
  }

  // Barometer not frozen? Nothing to do (normal flight path).
  if (g_baro->getLastReadingAgeMs() < BARO_STALE_AGE_MS) {
    g_bsSustainedCycles = 0;
    return false;
  }

  // Safety guards: the flight started and climbed above the ground guard
  // (maxAltitude from the last good baro reading).
  if (!g_bsLiftoffLatched ||
      g_baro->getMaxAltitude() <= BARO_STALE_MIN_HEIGHT) {
    g_bsSustainedCycles = 0;
    return false;
  }

  float ax, ay, az;
  g_imu->getAcceleration(&ax, &ay, &az);
  if (!std::isfinite(ax) || !std::isfinite(ay) || !std::isfinite(az)) {
    return false;
  }

  // Own IIR low-pass, same alpha as everywhere else (seed on first reading).
  if (!g_baroStaleFilterSeeded) {
    g_bsFiltAx = ax;
    g_bsFiltAy = ay;
    g_bsFiltAz = az;
    g_baroStaleFilterSeeded = true;
  } else {
    g_bsFiltAx += FILTER_ALPHA * (ax - g_bsFiltAx);
    g_bsFiltAy += FILTER_ALPHA * (ay - g_bsFiltAy);
    g_bsFiltAz += FILTER_ALPHA * (az - g_bsFiltAz);
  }

  const float acc = sqrtf(g_bsFiltAx * g_bsFiltAx +
                          g_bsFiltAy * g_bsFiltAy +
                          g_bsFiltAz * g_bsFiltAz);
  if (!std::isfinite(acc)) {
    return false;
  }

  if (acc > LIFTOFF_ACCEL_THRESHOLD) {
    g_bsLiftoffLatched = true;
  }

  if (acc < BARO_STALE_ACC_THRESHOLD) {
    g_bsSustainedCycles++;
    if (g_bsSustainedCycles >= BARO_STALE_SUSTAIN_CYCLES) {
      Serial.printf("[FlightControl] CONTINGENCY: baro stale %lu ms, "
                    "IMU-only free-fall acc=%.2f\n",
                    (unsigned long)(g_baro->getLastReadingAgeMs()), acc);
      return true;
    }
  } else {
    g_bsSustainedCycles = 0;
  }
  return false;
}
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

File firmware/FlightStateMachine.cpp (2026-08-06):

/**
 * @file FlightStateMachine.cpp
 * @brief Flight State Machine implementation
 *
 * All detection logic is a direct port from test/FSM/FSM.ino (the
 * validated Arduino test sketch). Threshold values are identical to
 * those validated against real flight data in
 * extras/FSM_tester/FSM_Tester.py and extras/FSM_tester/13_30_11-Dados.csv.
 *
 * State machine:
 *   IDLE → (liftoff) → ASCENT → (apogee) → DESCENT → (landed) → LANDED
 *
 * Within ASCENT: burnout event is flagged (no state change).
 * Within DESCENT: freefall and parachute events are flagged (no state change).
 *
 * @see FlightStateMachine.h for class and threshold documentation
 * @see test/FSM/FSM.ino lines 76–117 — original detection functions
 */

#include "flight/FlightStateMachine.h"
#include "config.h"
#include <Preferences.h>

// NVS keys (defined out-of-line — static const char* const members)
const char* const FlightStateMachine::NVS_NAMESPACE = "flight";
const char* const FlightStateMachine::NVS_KEY       = "fsm";

// ─────────────────────────────────────────────────────────────────────────────
// Constructor / lifecycle
// ─────────────────────────────────────────────────────────────────────────────

FlightStateMachine::FlightStateMachine(BMP585Sensor* baro, LSM6DS3Sensor* imu)
    : _baro(baro),
      _imu(imu),
      _state(IDLE),
      _ready(false),
      _liftoffDetected(false),
      _burnoutDetected(false),
      _apogeeDetected(false),
      _freefallDetected(false),
      _parachuteDeployed(false),
      _parachuteConfirmCount(0),
      _filtAx(0.0f),
      _filtAy(0.0f),
      _filtAz(0.0f),
      _firstReading(true) {}

bool FlightStateMachine::begin() {
  if (!_baro || !_imu) {
    Serial.println("[FSM] ERROR: null sensor pointer");
    return false;
  }
  _ready = true;
  // After a watchdog reboot mid-flight, resume where the FSM was instead of
  // starting over at IDLE (which would never re-arm and never deploy).
  restoreFromNVS();
  // Always persist the current state + launch reference so a later reboot
  // has a valid snapshot to restore.
  persistToNVS();
  Serial.println("[FSM] Ready");
  return true;
}

bool FlightStateMachine::isReady() {
  return _ready;
}

void FlightStateMachine::reset() {
  _state            = IDLE;
  _liftoffDetected  = false;
  _burnoutDetected  = false;
  _apogeeDetected   = false;
  _freefallDetected = false;
  _parachuteDeployed = false;
  _parachuteConfirmCount = 0;
  _filtAx = _filtAy = _filtAz = 0.0f;
  _firstReading = true;
  // Clear the persisted snapshot so the next boot starts fresh at IDLE.
  Preferences prefs;
  if (prefs.begin(NVS_NAMESPACE, false)) {
    prefs.remove(NVS_KEY);
    prefs.end();
  }
  Serial.println("[FSM] Reset -> IDLE (NVS cleared)");
}

// ─────────────────────────────────────────────────────────────────────────────
// Main update — called at 50 Hz from FlightControlTask
// ─────────────────────────────────────────────────────────────────────────────

void FlightStateMachine::update() {
  if (!_ready || !_baro->isReady() || !_imu->isReady()) return;

  const float height = _baro->getAltitude();
  const float vz     = _baro->getVerticalVelocity();

  float ax, ay, az;
  _imu->getAcceleration(&ax, &ay, &az);

  // Reject corrupt sensor frames before any computation
  if (!std::isfinite(height) || !std::isfinite(vz) ||
      !std::isfinite(ax)     || !std::isfinite(ay)  || !std::isfinite(az)) {
    return;
  }

  // IIR low-pass filter on accelerometer (ALPHA=0.2 — matches test/FSM/FSM.ino)
  // On first reading, seed the filter with the raw value so the filter state
  // starts at a real measurement rather than 0.
  if (_firstReading) {
    _filtAx = ax;
    _filtAy = ay;
    _filtAz = az;
    _firstReading = false;
  } else {
    _filtAx = smoothFilter(ax, _filtAx);
    _filtAy = smoothFilter(ay, _filtAy);
    _filtAz = smoothFilter(az, _filtAz);
  }

  const float acc = totalAccel(_filtAx, _filtAy, _filtAz);
  if (!std::isfinite(acc)) return;

  // ── State machine ────────────────────────────────────────────────────────

  switch (_state) {

    case IDLE:
      if (!_liftoffDetected && detectLiftoff(_filtAx, _filtAy, _filtAz)) {
        _liftoffDetected = true;
        transitionTo(ASCENT);
      }
      break;

    case ASCENT:
      // Burnout is an informational sub-event; it does not change the state.
      if (!_burnoutDetected && detectBurnout(_filtAx, _filtAy, _filtAz, height, vz)) {
        _burnoutDetected = true;
        Serial.printf("[FSM] BURNOUT  h=%.1f vz=%.2f acc=%.2f\n", height, vz, acc);
      }
      // Apogee by vz only, single cycle. The az gate was removed (risk #5):
      // apparent acceleration includes centripetal/pendulum terms and the
      // accelerometer may have bias (real flight: az at rest = +2.81 m/s²),
      // so filtered az can stay above -0.1 at the true apogee and the gate
      // would lose it entirely. 50Hz quantization noise makes |vz| briefly
      // cross zero before the real apogee — benign: the deploy gate below
      // (vz < -2 m/s sustained) still only fires on the real descent.
      // Validated: extras/FSM_tester/validate_50hz_noise.py (0 premature
      // deploys) and analyze_apogee_robustness.py.
      if (!_apogeeDetected && detectApogee(vz)) {
        _apogeeDetected = true;
        _parachuteConfirmCount = 0;  // Reset deploy confirmation at apogee
        transitionTo(DESCENT);
      }
      break;

    case DESCENT:
      // Freefall is an informational sub-event within descent.
      if (!_freefallDetected && detectFreefall(vz, height, acc)) {
        _freefallDetected = true;
        Serial.printf("[FSM] FREEFALL h=%.1f vz=%.2f acc=%.2f\n", height, vz, acc);
      }
      // Option A: deploy immediately after apogee, but only once descent is
      // confirmed by a stable negative Vz (PARACHUTE_CONFIRM_CYCLES samples)
      // and above the ground guard. Never deploys on ascent or near ground.
      if (!_parachuteDeployed && detectParachute(height, vz)) {
        if (++_parachuteConfirmCount >= PARACHUTE_CONFIRM_CYCLES) {
          _parachuteDeployed = true;
          persistToNVS();  // safety-critical: survive a reboot right after deploy
          Serial.printf("[FSM] PARACHUTE DEPLOYED h=%.1f vz=%.2f\n", height, vz);
        }
      } else {
        _parachuteConfirmCount = 0;
      }
      if (detectLanded(vz, height)) {
        transitionTo(LANDED);
      }
      break;

    case LANDED:
      // Terminal state — awaits explicit reset()
      break;
  }
}

// ─────────────────────────────────────────────────────────────────────────────
// ISensor::getData
// ─────────────────────────────────────────────────────────────────────────────
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

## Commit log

2026-03-18 refactor: modularize firmware into separate headers with English documentation
    The monolithic firmware.ino (584 lines) has reached EOL and was refactored into 11 modular files for improved maintainability and easier future modifications (e.g., BMP280->BMP585 sensor upgrade, FSM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
    Changes:
    - Split firmware into dedicated module headers (sensors, communication, control)
    - Reduced main firmware.ino from 584 to 79 lines (86% reduction)
    - Added comprehensive Doxygen-style English documentation to all modules
    - Created config.h for centralized configuration management
    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
2026-03-18 docs: add comprehensive refactoring plan for POO + FreeRTOS + FSM
    Created detailed planning document (REFACTORING_PLAN.md) outlining the complete architecture and implementation strategy for the firmware refactoring.
    Key contents:
    - Architecture decisions (POO selective, FreeRTOS tasks, FSM)
    - Complete directory structure (sensors/, flight/, modules/)
    - 9-phase implementation plan (16.25h total estimated)
    - FSM state diagram (6 states: IDLE→LIFTOFF→BURNOUT→APOGEE→FREEFALL→LANDED)
    - FreeRTOS task configuration (FlightControl 50Hz, Telemetry 5Hz, Logger)
    - Sensor migration plan (BMP280→BMP585, MPU6050→LSM6DS3, GPS N6M→N8M)
    - Data structures (SensorData queue, LogMessage queue)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
2026-03-18 feat: add validated FSM tester with real flight data
    - Add FSM_Tester.py: Complete Python implementation with 7-state FSM
    - Add 13_30_11-Dados.csv: Real flight telemetry data (1,873 points)
    - Add explicacao.md: Complete FSM documentation with line references
    - Add filtered/simulated datasets for testing
    - Add Jupyter notebook for CSV analysis
    This implementation serves as the validated reference for C++ translation
    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
2026-03-18 add csv data
    [13_30_11-Dados.csv, dados_filtrados.csv, dados_simulados.csv]
2026-03-24 Maquina de estado para o esp32
    - flight_inserter.py : codigo que injeta o log do voo no arduino e pega o output do esp e printa no terminal
    - FMS.ino : codigo que recebe pelo serial os logs do python e calcula em que estado o foguete esta
2026-03-24 FMS arduino com flight inserter corrigidos
    [flight_inserter.py]
2026-03-26 fix: FMS.ino coloquei as variaveis prev com globais e pq precisei juntar elas a funcao de reset
    arquivos: FSM.ino esta em test/FSM
    [flight_inserter.py]
2026-04-07 refactor: fix OpenCode configuration and skills structure
    - Fixed .opencode/README.md: correct skill directory structure (.md → /SKILL.md)
    - Created .opencode/opencode.yaml: central configuration file with 6 skills, 3 workflows
    - Created .opencode/SKILLS_INDEX.md: centralized skills index and quick reference guide
    - Updated AGENTS.md: added opencode.yaml references and clarified skill locations
    All skills validated:
    ✅ embedded-architect/SKILL.md
    ✅ firmware-developer/SKILL.md
    ✅ fsm-specialist/SKILL.md
    ✅ code-reviewer/SKILL.md
    ✅ test-engineer/SKILL.md
    ✅ documentation-specialist/SKILL.md
    OpenCode integration now fully functional. Skills can be properly loaded and accessed.
2026-04-07 refactor: implement Phase 1 & 2 - project structure and base interfaces
    - Create firmware/sensors/ and firmware/flight/ directories for OOP refactoring
    - Implement ISensor abstract base interface for all sensors
    - Create SensorData struct with telemetry fields and FlightState enum
    - Create LogMessage struct for thread-safe logging via FreeRTOS queues
    - Add helper functions: getFlightStateName() and getLogLevelName()
    - All interfaces validated with Doxygen documentation comments
2026-04-07 refactor: improve Phase 1-2 documentation and examples
    - Add example usage code to ISensor interface (BMP585Sensor pattern)
    - Add detailed docstring explanations for all virtual methods
    - Add @see references to REFACTORING_PLAN.md for architecture details
    - Document actual struct memory size (96 bytes for SensorData vs 64 estimated)
    - Add notes on queue memory calculation and RAM budget impact
    - All changes validated by Embedded Architecture review
2026-04-07 fix: add critical safety initializations to SensorData structs
    **CRITICAL SECURITY FIXES:**
    1. Initialize SensorData struct with safe defaults
    - All float fields initialized (altitude, accelX/Y/Z, etc.)
    - accelZ initialized to 9.81 m/s² (gravity) to avoid NaN in FSM
    - parachute_deployed initialized to false
    - Prevents undefined behavior and parachute deployment failures
    2. Initialize LogMessage struct safely
    - Buffer memset to '\0' to prevent overflow
    - All fields initialized to avoid garbage values in logs
    - Prevents corrupted telemetry logging
    3. Add #include <cstring> for memset() in SensorData.h
    All initializations are safe for FreeRTOS queues and prevent:
    - NaN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
2026-04-07 docs: implement P2 and P3 recommendations - complete ISensor and SensorData documentation
    **P2: Add Usage Examples (ISensor.h)**
    - Added comprehensive @example block with 2 real-world scenarios
    - Example 1: Full BMP585Sensor implementation pattern
    - Shows proper sensor class structure
    - Demonstrates all 4 ISensor methods
    - Clear error handling pattern
    - Example 2: FreeRTOS task integration (50Hz)
    - Shows FlightControlTask pattern for high-priority sensors
    - Demonstrates non-blocking update() requirement
    - Explains vTaskDelayUntil for periodic execution
    - Added @note warnings about non-blocking requirement
    **P3: Add Cross-References (Both files)**
    ISensor.h:
    - @see firmware/REFA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
2026-04-23 feat(web): restaurar assets da interface no LittleFS
    - adiciona novamente os arquivos estáticos da interface web (HTML, CSS e JS)
    - corrige falha em runtime causada por rotas válidas apontando para assets ausentes
    - mantém compatibilidade com as rotas já existentes do servidor
    - reativa fluxo de listagem, visualização, download e exclusão de arquivos pela UI
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2026-04-23 - printBoth() agora aceita um parâmetro opcional beep com default true.
    - logData() passa false, então cada pacote de telemetria não toca mais o buzzer.
    - Mensagens de status/erro continuam podendo usar beep normalmente quando chamarem printBoth() sem o segundo argumento.
2026-04-29 fix(copilot-review): implement LSM6DS3 validation ranges and vector accessors (Issue #6)
    - LSM6DS3Sensor.h: Add vector accessor methods (getAcceleration, getGyroscope) for direct accel/gyro access (Issue #6)
    - LSM6DS3Sensor.cpp: Implement realistic range validation (200 m/s² accel, 2000 °/s gyro) to prevent corrupted samples from reaching FSM (Issue #6)
    - telemetry_module.h/cpp: Update documentation and integrate LSM6DS3 sensor with fallback to MPU6050 for compatibility (v2.0 migration)
    - firmware.ino: Add global LSM6DS3 instance and initialization in setup(), update sensor readings in main loop
    These changes address all Copilot review comments:
    - Parachute module: forward declaration of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
    [LSM6DS3Sensor.cpp, firmware.ino]
2026-04-29 chore: remove firmware/data/server assets (no longer used in v2.0)
    The web server assets (index.html, style.css, index.js) are not being
    used in the current v2.0 implementation and have been removed to clean up
    the repository. The server_module.h routes will serve content directly
    (HTML inline or from other sources as needed).
    Removed:
    - firmware/data/server/index.html
    - firmware/data/server/style.css
    - firmware/data/server/index.js
2026-05-05 docs: align refactor plan and issues backlog with current progress
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2026-05-07 docs: update documentation to reflect v2.0 progress and rename to #11
    - Update docs/software.md: phases now show 1-5 complete, FSM with 4 states
    - Update docs/adr/002-sensor-abstraction.md: all sensor phases marked complete
    - Update AGENTS.md, REFACTORING_PLAN.md, firmware files: rename Team #100 to #11
    - Add Phase 6-9 planned items to documentation
    - Fix FSM diagram: 7-state to 4-state (IDLE→ASCENT→DESCENT→LANDED)
    - Update structure to reflect pending flight/ tasks (Phase 6+)
    [config.h, firmware.ino]
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2026-07-10 fix final: 1 - string fix 2 - heap fragmentation via string em assembletelemetry 3 - team id fix 4 - servo position naming 5 - wdt init antes da criacao da task
    [FlightControlTask.cpp, TelemetryTask.cpp, config.h]
2026-07-17 1 - firmware.ino : fix de inicializar setup de forma segura e usando a funcao init de cada task
    2 - setupServo() nao existia feedback caso desse problema
    [FlightControlTask.cpp, firmware.ino]
2026-07-17 #19 1 - inicilizacao do buzzer
    [FlightControlTask.cpp]
2026-07-17 fix: deploy parachute at apogee instead of 100m ceiling (Option A)
    Replace the old 100m-ceiling trigger with apogee-based deployment: the chute now opens immediately after apogee is confirmed (stable negative Vz for PARACHUTE_CONFIRM_CYCLES samples), at whatever altitude the apogee occurs. Never deploys on ascent or near ground (PARACHUTE_MIN_ALTITUDE ground guard).
    Validation (extras/FSM_tester):
    - validate_parachute_option_a.py: synthetic low/high apogee + bench vibration -> PASS
    - validate_parachute_realflight.py: RocketPy sim (~951m apogee, deploy at 949m) and real flight (~272m apogeu, deploy at 268m) -> PASS
    [FlightStateMachine.cpp, config.h, validate_parachute_option_a.py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]
2026-07-17 refactor: remove dead parachute_module.h code (Fase 9)
    parachute_module.h was orphaned and non-compilable: handleParachute() referenced max_altitude/previous_altitude (now private to BMP585Sensor) and printBoth() (never defined after telemetry_module.h removal). The deployment decision already lives in FlightStateMachine (apogee, Option A) and is acted on by FlightControlTask.
    - parachute_module.h: drop handleParachute/printBoth and duplicated deploy globals; module now owns only the servo actuator (ParachuteServo) and setupServo()
    - setupServo(): fix attach() check (ESP32Servo::attach returns bool, not int)
    - FlightControlTask.cpp: remove local g_parachuteServo; deployParachute()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
    [FlightControlTask.cpp, firmware.ino]
2026-07-17 docs: clean firmware.ino orphans and sync REFACTORING_PLAN Fase 8
    Fase 8 cleanup:
    - firmware.ino: remove dead global sensor/queue pointers (baroSensor, imuSensor, gpsModule, flightFSM, sensorDataQueue, logQueue) that were never used (each init*Task() owns its objects). Fix missing semicolon on pinMode(BUZZER_PIN, OUTPUT) (was a compile error). Update file header and setup()/loop() docs to v2.0 reality (BMP585, LSM6DS3 only, 50Hz FlightControl / 5Hz Telemetry+Logger, apogee-based parachute).
    - REFACTORING_PLAN.md Fase 8: mark Concluida and document the real architecture (init functions own objects, TWDT armed inside taskFlightControl, queue drain keeps newest sample, constants in config.h).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
    [firmware.ino]
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2026-07-18 docs: rewrite MODULOS.md and sync REFACTORING_PLAN Fase 6
    Documentation sync after the v2.0 refactor:
    - MODULOS.md: full rewrite to reflect the real v2.0 architecture
    (sensors/ ISensor layer: BMP585/LSM6DS3/GPS; modules/: parachute/lora/
    buzzer/filesystem; flight/: FSM + 3 FreeRTOS tasks). Removes the obsolete
    bmp280/mpu6050/telemetry_module/server sections that no longer exist.
    - REFACTORING_PLAN.md Fase 6: update from the naive 4-state sketch to the
    implemented model (4 outer states + 7 sub-event flags: liftoff, burnout,
    apogee, freefall, parachute). Replace detectDescent(vz<0)+deploy-on-DESCENT
    with the real Option A (detectParachute at apogee, validated with RocketPy
    + rea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
2026-07-18 docs: sync docs/ and README/CONTRIBUTING to v2.0 (issue #22)
    Update project documentation to reflect the completed v2.0 architecture (Phases 1-10):
    - docs/software.md: full rewrite. FreeRTOS tasks (FlightControl 50Hz/Core1,
    Telemetry 5Hz/Core0, Logger low), queues, ISensor hierarchy (BMP585/
    LSM6DS3/GPS), FSM 4 outer states + 7 sub-events, parachute Option A at
    apogee, LoRa 915 MHz params, LittleFS 22-field CSV, build/test notes.
    Removes all v1.0 references (BMP280, MPU6050, handleParachute,
    ALTITUDE_THRESHOLD 750m, WebServer). ESP32-S3 as v2.0 target.
    - docs/hardware.md: components updated to real BOM (BMP585, LSM6DS3, NEO-8M,
    RFM95W 915 MHz), pinout from config.h, block diagra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
2026-07-19 build: fix ESP32-S3 compilation and restore Arduino IDE build
    The previous agent restructured sources into firmware/src/ (PlatformIO layout),
    which breaks the Arduino IDE / arduino-cli build (subfolders are not
    recursed for .cpp). Revert to the documented Arduino layout:
    - Move implementation files (.cpp) to the sketch root (firmware/) so the
    Arduino build compiles and links them. Headers (.h) stay in subfolders
    (sensors/, flight/, modules/) for organization.
    - Remove the temporary #include of .cpp from firmware.ino (caused
    anonymous-namespace g_stats collisions across concatenated TUs).
    - Carry over the agent's legitimate compile fixes: Adafruit_LSM6DS ->
    Adafruit_LSM6DS class, beg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
    [BMP585Sensor.cpp, FlightControlTask.cpp, FlightStateMachine.cpp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]
2026-07-19 General update
    [electronics.kicad_pcb, electronics.kicad_sch, m3_nut.SLDPRT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]
2026-08-05 feat: persist FSM state in NVS to survive mid-flight watchdog reboot
    A watchdog reset mid-flight lost the FSM state and re-leveled the BMP585
    at the reboot point, so the parachute never deployed. Persist a snapshot
    (state, flags, confirm counter, launch base_pressure, maxAltitude) to
    NVS on every transition, on deploy and at boot; restoreFromNVS() resumes
    ASCENT/DESCENT and setupServo(keepOpen) leaves the servo open if the
    chute was already released.
    Validated: arduino-cli compile (esp32s3 + esp32c3), parachute realflight
    validator PASS, new validate_watchdog_reboot.py PASS on all 9 scenarios.
    [BMP585Sensor.cpp, FlightControlTask.cpp, FlightStateMachine.cpp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]
2026-08-06 fix: detectar apogeu só por |vz| — remover gate de az (risco nº5)
    O gate de az (APOGEE_AZ_THRESHOLD=-0.1) era o elo fraco da detecção de
    apogeu: o acelerômetro mede aceleração aparente (gravidade + centrípeta +
    aero) e, no voo real (~272 m), a margem sobre o threshold era de apenas
    ~0.81 m/s² — bamboleio pendular pós-burnout >= 1.1 m/s² @1 Hz fazia o
    apogeu NUNCA ser detectado (FSM presa em ASCENT, deploy só via backstop,
    1-3 s atrasado). análise: extras/FSM_tester/analyze_apogee_robustness.py.
    detectApogee() agora é só |vz| < 1.0 m/s: vz vem da altitude barométrica
    (não do acelerômetro) -> imune ao bamboleio por construção. Ruído de
    quantização a 50Hz pode cruzar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
    [FlightStateMachine.cpp, analyze_apogee_robustness.py, config.h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]
2026-08-06 feat: contingência barômetro congelado — staleness + free-fall IMU-only (risco nº1)
    Se o barômetro congela em voo (glitch I2C, solda ruim, EMI), FSM e backstop
    perdem vz/altitude juntos — e o update() preserva o último valor bom (plausível,
    nenhum NaN pega). Sem contingência, NENHUMA camada abriria o paraquedas.
    - BMP585Sensor::getLastReadingAgeMs(): idade da última leitura válida
    (_prevTime só avança com leitura válida)
    - checkBaroStaleContingency() no FlightControlTask (FSM-independente, como o
    backstop): barômetro sem leitura válida por >2s + liftoff já visto
    (acc > 15 m/s² desde o boot) + maxAltitude (último valor bom) > 50 m +
    acc filtrado < 3 m/s² por 2.5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
    [BMP585Sensor.cpp, FlightControlTask.cpp, config.h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]
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2026-08-06 test: validar FSM nas simulacoes dos 2 proximos voos (thonyan ~682m, dedalo ~1544m)
    Simulacoes RocketPy dos 2 voos que serao feitos com esta telemetria
    (flight_results_*.csv). Rodam em toda a suite de validadores:
    - deploy no apogeu: thonyan t=11.86s h=681.8m (real 11.94s) | dedalo
    t=17.8s h=1543.9m (real 17.88s) — PASS, 360ms apos o apogeu
    - backstop e contingencia baro_stale inofensivos em voo normal — PASS
    - watchdog: reboot em qualquer fase -> deploy no mesmo tempo — PASS
    - estresse 50Hz: 100% de deteccao, 0 deploys prematuros — PASS
    Nota: simulacoes RocketPy usam passo adaptativo de ~2ms na subida; o
    firmware roda a 50Hz fixo. Com dt de 2ms o vz por diferenca fica < 1 m/s
    lo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
    [flight_results_dedalo.csv, flight_results_thonyan.csv]
2026-08-06 feat: armamento na rampa (risco nº2) — comando ARM limpa NVS + re-captura base_pressure
    Problema: vibracao de bancada (13_30_11: spikes 22-122 m/s2) dispara
    liftoff FALSO -> FSM em ASCENT. Reboot antes de LANDED restaura ASCENT
    do NVS -> na rampa, |vz|~0 dispara apogeu -> DESCENT -> LANDED: o
    paraquedas NUNCA abre no voo real. E base_pressure capturada 1x no
    boot desloca a altitude com o drift (~1 hPa/dia ~ 8.4 m).
    Fix (validado em Python antes do C++: validate_arming.py, 10 cenarios):
    - Comando 'ARM' via Serial (no pad): fsm.reset() (IDLE + NVS limpo),
    re-captura base_pressure da leitura atual, zera maxAltitude.
    Recusado se o voo ja comecou (maxAltitude >= ARM_MAX_ARM_ALTITUDE)
    ou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
    [FlightControlTask.cpp, config.h, validate_arming.py]
2026-08-06 test: bancada do servo do paraquedas sob carga real (risco nº4)
    O firmware abre a porta com write(SERVO_OPEN) sem feedback (sem fim de
    curso, sem corrente). Se a porta travar ou o velame exigir mais torque,
    o servo trava (stall) sem o firmware perceber — e o paraquedas nao abre
    no apogeu.
    Sketch test/parachute_servo/parachute_servo.ino: varredura OPEN/CLOSE
    com carga real (porta + velame + elastico), microswitch opcional de fim
    de curso (fixture de bancada), probe 'b' para corrente de stall com
    multimetro, 20 tentativas com criterios de aprovacao (abertura
    completa, tempo < limite, hold sem back-drive).
    Analisador extras/FSM_tester/analyze_servo_open_times.py: estatistica
    (media, desvio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
    [analyze_servo_open_times.py, parachute_servo.ino]
2026-08-07 fix: configurar barramento SPI no setup antes do SD
    initTelemetryTask() chama setupStorage() (SD.begin) antes de setupLoRa(),
    mas o SPI so e' configurado dentro do setupLoRa() — resultado: SD.begin()
    usava os pinos SPI default do ESP32-S3 e sempre caia no fallback LittleFS.
    Correcao: SPI.begin(LORA_SCK, LORA_MISO, LORA_MOSI, SS_LORA) no setup()
    do firmware.ino, antes de qualquer uso do barramento. O SPI.begin
    repetido em setupLoRa() e idempotente (mesmos pinos).
    Atualizado tambem o comentario da setupStorage() em filesystem_module.h
    que estava invertido (atribuia a config SPI a si mesma).
    [firmware.ino]
2026-08-17 fix: alinhar pinout config.h com esquematico ESP32-S3 (12 nets corrigidas)
    Auditoria pin-a-pin entre hardware/electronics/electronics/electronics.kicad_sch
    e firmware/config.h revelou 12 de 13 nets de sinal com GPIO errado (SDA/SCL ja
    bate). Pinout antigo do config.h era do HELIKE pre-migracao para
    ESP32-S3-DEVKITC-1-N8R8 e nao foi atualizado.
    Atualizado:
    SPI SCK 4->12, MISO 2->13, MOSI 3->11, CS_LORA 5->10
    LoRa RST 6->4, DIO0 7->5
    SD CS 12->14
    SERVO 10->7 (M1 e M2 no esquematico compartilham o mesmo pino)
    BUZZ 11->6
    GPS RX 20->18, TX 21->17
    Comentarios em config.h e firmware.ino agora referenciam o esquematico e
    removem a nota 'adjust to match the final schematic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
    [config.h, firmware.ino]
2026-08-19 Update flight-computer hardware files
    [electronics.kicad_pcb, electronics.kicad_sch]
2026-08-20 Update flight-computer hardware files (PCB)
    [electronics.kicad_pcb, electronics.kicad_sch, electronics.step]
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2026-08-27 fix: LSM6DS3 member was base class Adafruit_LSM6DS (init always failed)
    The _lsm member was declared as the BASE class Adafruit_LSM6DS, whose
    _init() returns false unconditionally (only derived classes override it
    with a WHOAMI check). begin_I2C() therefore always failed on hardware
    even though the IMU was alive at 0x6B (WHO_AM_I=0x69 confirmed by raw
    probe). Declare it as Adafruit_LSM6DS3.
    Also: pass &Wire explicitly to begin_I2C, add boot debug prints, and
    init the IMU before the barometer (most critical sensor for the FSM).
    Bench: LSM6DS3 @0x6B PASS, accel 9.85 m/s2 at rest, bus healthy.
    [FlightControlTask.cpp, LSM6DS3Sensor.cpp]
2026-08-27 fix: throttle flash logging to 1 Hz (I2C spinlock panic at 5 Hz)
    Bench crash after ~13 s: backtrace was taskFlightControl ->
    BMP585Sensor::update() -> BMP280 readPressure() -> i2c_master
    synchronous transaction -> xPortEnterCriticalTimeout panic.
    Root cause: flash writes (LittleFS/SD append + NVS) disable the flash
    cache on BOTH cores; while the cache is off, the 50 Hz I2C transaction
    on Core 1 stalls and the esp_driver_i2c spinlock times out. Writing at
    full 5 Hz made a cache-off window land mid-I2C near-certain.
    Fix: divide the telemetry flash append by 5 (1 Hz) in taskTelemetry;
    LoRa TX and Serial keep the 5 Hz cadence. Bench: 90 s continuous run,
    0 crashes, 447 telemetry cycles (previo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
    [TelemetryTask.cpp]
2026-08-27 docs: sync hardware.md pinout and I2C addresses with bench reality
    - Pin table was stale (old LoRa SPI 4/2/3, GPS 20/21, servo 10/buzzer 11):
    now matches config.h (LoRa SCK=12/MISO=13/MOSI=11/CS=10/RST=4/DIO0=5,
    servo=7, buzzer=6, SD CS=14, GPS RX=17/TX=18).
    - GPS note: TX line physically on GPIO17 — bench-measured 2026-08-27 with
    test/gps_diag raw sniffer; schematic comment was wrong. Validated with
    11 sats / 3D fix at 9600 baud.
    - BMP585 address 0x7E (bench) + BMP280 fallback documented; LSM6DS3 0x6B
    (bench; SDO strap selects 0x6A/0x6B).
2026-08-27 test: bench self-test suite + GPS raw sniffer
    test/bench/bench.ino: interactive dispatcher (a=all b=baro i=imu g=gps
    l=lora f=fs s=servo z=buzzer) exercising every sensor/module/actuator
    with PASS/FAIL verdicts. Latest run: 18 PASS / 5 FAIL, of which the GPS
    fails were the wiring swap (fixed in config.h) and BMP585 absence
    (fallback active). README records results and the mirror-of-config.h
    rule (which bit us once already).
    test/gps_diag/gps_diag.ino: raw UART sniffer, both pin orientations x
    4 bauds, RX-only (never drives the GPS lines). Proved the GPS TX line
    is physically on GPIO17 (clean NMEA @9600, 1468 bytes, 3D fix) while
    the schematic comment said GPIO18. Second schematic-vs-hardwar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
    [bench.ino, gps_diag.ino]
2026-08-27 fix: passive piezo needs square wave, not DC — 2700 Hz resonance
    The buzzer is a PASSIVE piezo: digitalWrite DC does not make it
    oscillate (only a faint click) — this was the 'low volume' symptom,
    not the PN2222A/220R driver (12 mA base current saturates fine).
    - config.h: BUZZER_TONE_HZ=2700, chosen from the bench resonance sweep
    (test/bench , 2.0-4.0 kHz scan; loudest at 2700 Hz).
    - buzzer_module.h: tone frequency 500 -> 2700 Hz via tone() (LEDC);
    documented that passive piezo requires a square wave.
    - bench.ino : PWM tones via ledcWriteTone (ESP32 core 3.x API) +
    resonance sweep so the frequency is data, not a guess.
    [bench.ino, config.h]
2026-08-28 docs: bench findings 2026-08-27 — F16 reproduced, pinout sync, servo angles
    FMECA / extraction doc (docs/extracao-eletronica-telemetria-payload.md):
    - F16 (5V rail collapse under servo peak) REPRODUCED on bench with the
    2S battery: Mini-560 (MP2315, nominal 5A) collapsed during ejection
    at 7.0V input while the PSU run was clean. Measured peak 0.4A /
    rest 0.06A — far below nominal, defective/counterfeit unit. Fixed by
    swapping to XL4015 5A: ejection works on battery. Effective RPN
    160->80 (D 8->4). XL4015 notes: async buck, 1.5-2V dropout — headroom
    tight at 2S end-of-discharge; Vbat monitoring stays recommended
    (deferred by user decision). Always verify the trimpot at 5.0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
    [config.h]
